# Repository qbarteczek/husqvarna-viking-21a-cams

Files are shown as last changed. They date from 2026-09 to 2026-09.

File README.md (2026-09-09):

# Generator bębnów ściegowych do Husqvarna 21E / Husqvarna 21E Stitch Drum Generator

*Dokument dwujęzyczny — polski niżej, English below. / Bilingual document — Polish first, English below.*

---

> [!TIP]
> ### 🌐 [URUCHOM GENERATOR BĘBNÓW ONLINE (BEZ INSTALOWANIA PROGRAMÓW)](https://qbarteczek.github.io/husqvarna-viking-21a-cams/)
> **Dla każdego użytkownika maszyny:** wybierz dowolne ściegi z katalogu kilkudziesięciu wzorów, zobacz bęben w 3D w czasie rzeczywistym i pobierz gotowy plik `.stl` do druku 3D jednym kliknięciem!
> 
> *English: [CLICK HERE TO LAUNCH THE 3D DRUM GENERATOR IN BROWSER (NO SOFTWARE NEEDED)](https://qbarteczek.github.io/husqvarna-viking-21a-cams/)*

---

## PL

Otwarty **generator** bębnów ściegowych (stitch cams) do maszyny **Husqvarna 21E**
(rodzina mechanizmu obejmuje też pokrewne oznaczenia: 19, 20, 21A). Nie jest to
zamknięty zestaw czterech wzorów — to parametryczna biblioteka i aplikacja internetowa, w której
mocowanie jest raz zweryfikowane i wspólne, a Ty projektujesz dowolną liczbę
własnych wzorów ściegów. Patrz [`docs/CREATING_NEW_DRUMS.md`](docs/CREATING_NEW_DRUMS.md).

### Cel

Zestaw A jest już zaprojektowany: [Viking 21a Basic Stitch Cam](https://www.thingiverse.com/thing:6018240)
autorstwa maxkrippler — zygzak + zygzak 3-stopniowy. Geometrię zweryfikowano dwoma
niezależnymi źródłami:

1. **Analiza pliku STL** zestawu A (skan promienia co 0.1–0.25 mm wzdłuż całej długości) —
   wykazała, że to nie płaska tarcza, tylko **krzywka bębnowa z profilowaną krawędzią**:
   - sama krawędź walca na każdej z 5 pozycji jest ukształtowana jako ząbki/profil ściegu
     (nie schowany rowek) — czujnik/popychacz maszyny jeździ bezpośrednio po tej krawędzi,
   - pozycje **sąsiadują bezpośrednio, bez żadnego odstępu**,
   - krzywka **nie ma otworu przelotowego na wałek** — ma za to gniazdo montażowe (otwór na
     wałek napędowy z wypustem blokującym obrót) w czole dużego kołnierza oraz osobny,
     wieloschodkowy trzpień montażowy między dużym kołnierzem a częścią zębatą.
2. **Zdjęcia fizycznego bębna A** (dostarczone przez użytkownika, patrz
   [`references/husqvarna_photos_A/`](references/husqvarna_photos_A/)) — ujawniły dodatkowo
   gwint na dużym kołnierzu, dokładny kształt wpustu w gnieździe i układ grawerunku
   ("HUSQVARNA SWEDEN" + litera zestawu).

Na tej podstawie zbudowano parametryczny generator OpenSCAD z trzema gotowymi, oryginalnymi
zestawami — **B1, C1, D** — z tą samą, zweryfikowaną geometrią mocowania. Zestawy A1, B1, C1
stanowią wierną rekonstrukcję historycznych bębnów fabrycznych z oficjalnej instrukcji
obsługi Husqvarna 21E (str. 31) oraz instrukcji serwisowej Class 21.

### Status

| Zestaw | Oznaczenie fabryczne | Źródło wzorów | Status |
|---|---|---|---|
| **A1** | `S 41-10950` | Instrukcja 21E (str. 31) + zdjęcia bębna A | Pełna rekonstrukcja fabryczna (`models/generated/cam_A.scad` + `.stl`) |
| **B1** | `S 41-10951` | Instrukcja 21E (str. 31: *Grunnmönster B1*) | Pełna rekonstrukcja fabryczna (`models/generated/cam_B.scad` + `.stl`) |
| **C1** | `S 41-10952` | Instrukcja 21E (str. 31: *Grunnmönster C1*) | Pełna rekonstrukcja fabryczna (`models/generated/cam_C.scad` + `.stl`) |
| **D**  | — | Wzór autorski (ściegi użytkowe specjalne) | Wygenerowany (`models/generated/cam_D.scad` + `.stl`) |

Element pomocniczy [`tools/openscad/mating_shaft_reference.scad`](tools/openscad/mating_shaft_reference.scad)
— testowy trzpień do sprawdzenia dopasowania otworu i wpustu przed drukiem całego bębna.

### Generator nowych bębnów (Stitch Drum Generator)

Projekt zawiera uniwersalny generator umożliwiający stworzenie własnego bębna z **katalogu ponad 35 znanych ściegów** (użytkowe, elastyczne, ozdobne fale, satynowe romby, meandry i szachownice):
1. **🌐 Interaktywna aplikacja online ([https://qbarteczek.github.io/husqvarna-viking-21a-cams/](https://qbarteczek.github.io/husqvarna-viking-21a-cams/)):**
   - **Podgląd 3D w czasie rzeczywistym (WebGL / Three.js):** natychmiastowe obracanie i oglądanie bębna (koniec z czekaniem 30–40 s na renderowanie OpenSCAD),
   - **Bezpośrednie generowanie STL:** klikasz „Pobierz plik STL do druku 3D” i w 0.01 sekundy pobierasz gotowy plik `.stl` gotowy do slicera (Cura, PrusaSlicer, Bambu Studio),
   - **Symulacja przeszycia na tkaninie:** podgląd nici igłowej na żywo dla 5 pozycji bębna,
   - **Offline:** dwuklik w plik `Uruchom_Generator.bat` w katalogu projektu.
2. **Panel okienkowy OpenSCAD Customizer GUI** ([`tools/openscad/cam_generator.scad`](tools/openscad/cam_generator.scad)): rozwijane menu wyboru ściegów dla każdej pozycji bezpośrednio w OpenSCAD bez pisania kodu.
3. **Skrypt wsadowy PowerShell** ([`tools/generator/generate_drum.ps1`](tools/generator/generate_drum.ps1)): automatyczne generowanie kodu i kompilacja siatki STL z wiersza poleceń.

Szczegółowy podręcznik użytkownika: [`docs/GENERATOR.md`](docs/GENERATOR.md) / [`docs/GENERATOR.en.md`](docs/GENERATOR.en.md).
Zobacz też: [`docs/CREATING_NEW_DRUMS.md`](docs/CREATING_NEW_DRUMS.md) dla projektowania własnych funkcji matematycznych.

### Podgląd

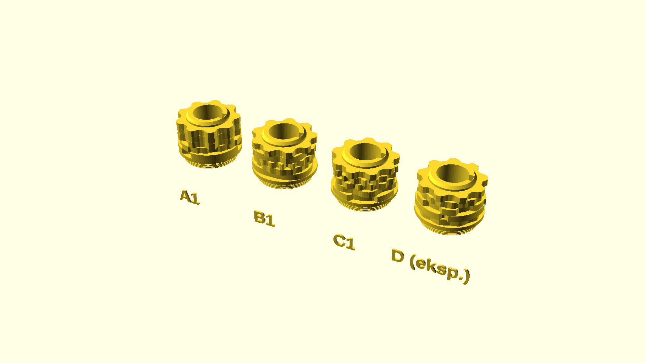
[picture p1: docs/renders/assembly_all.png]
Zestawienie A1/B1/C1/D


| Bęben | Widok izometryczny 3D | Czoło z grawerunkiem i wpustem |
|:---:|:---:|:---:|
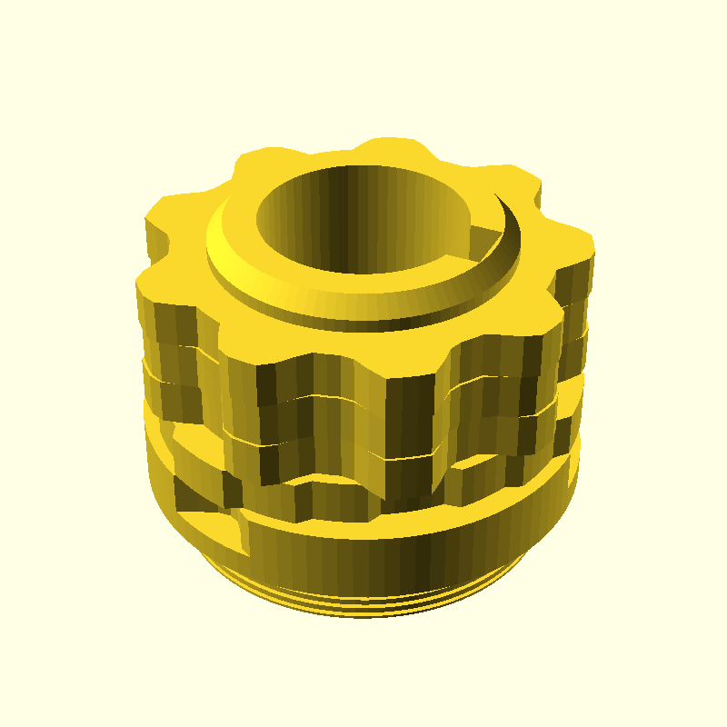
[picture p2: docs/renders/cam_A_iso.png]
A1 iso
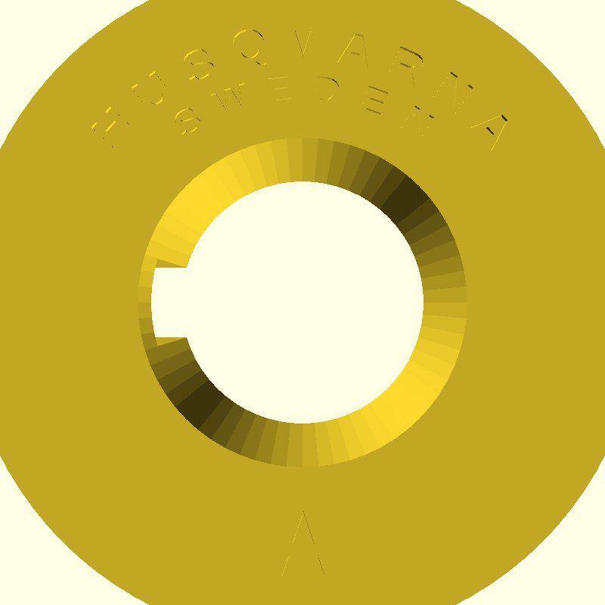
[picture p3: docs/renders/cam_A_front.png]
A1 czoło
| **A1** (fabryczny) |  |  |
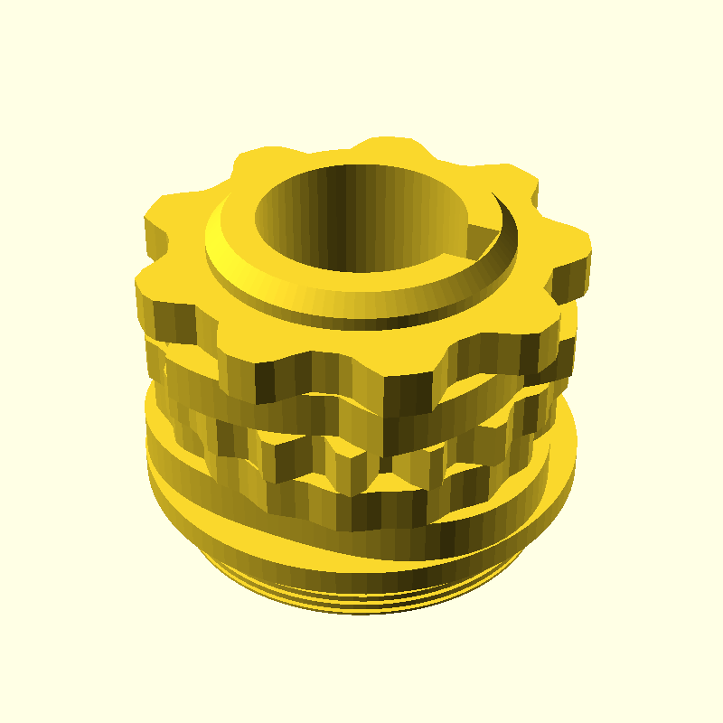
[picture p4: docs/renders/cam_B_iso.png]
B1 iso
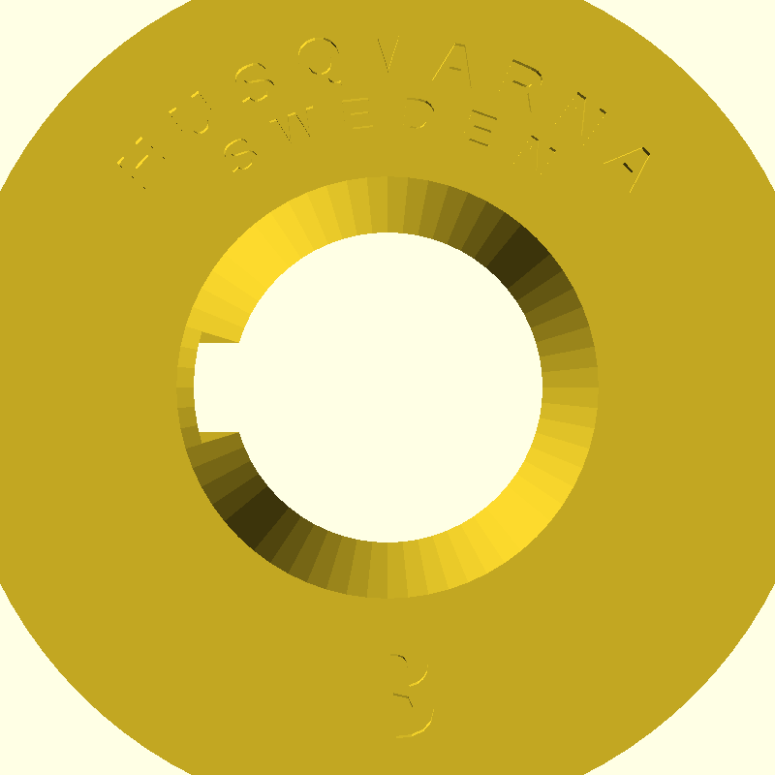
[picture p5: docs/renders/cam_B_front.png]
B1 czoło
| **B1** (fabryczny) |  |  |
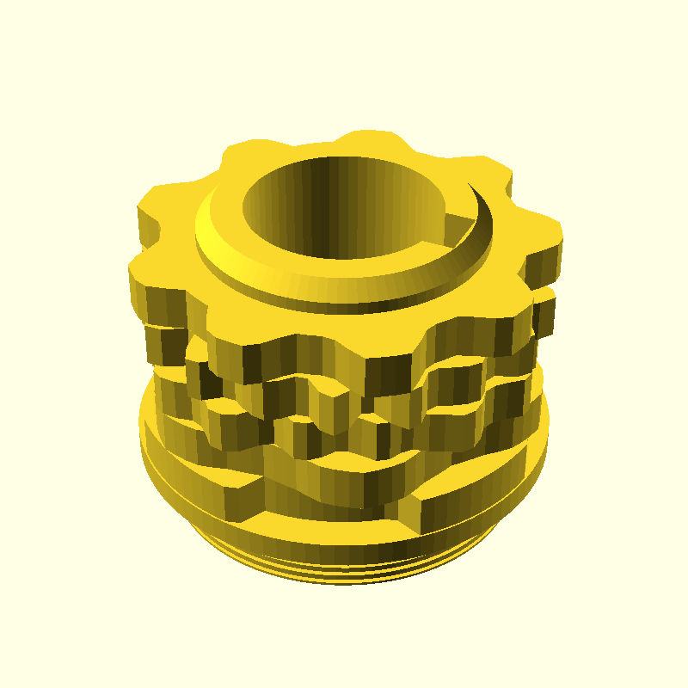
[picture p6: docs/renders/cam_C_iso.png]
C1 iso
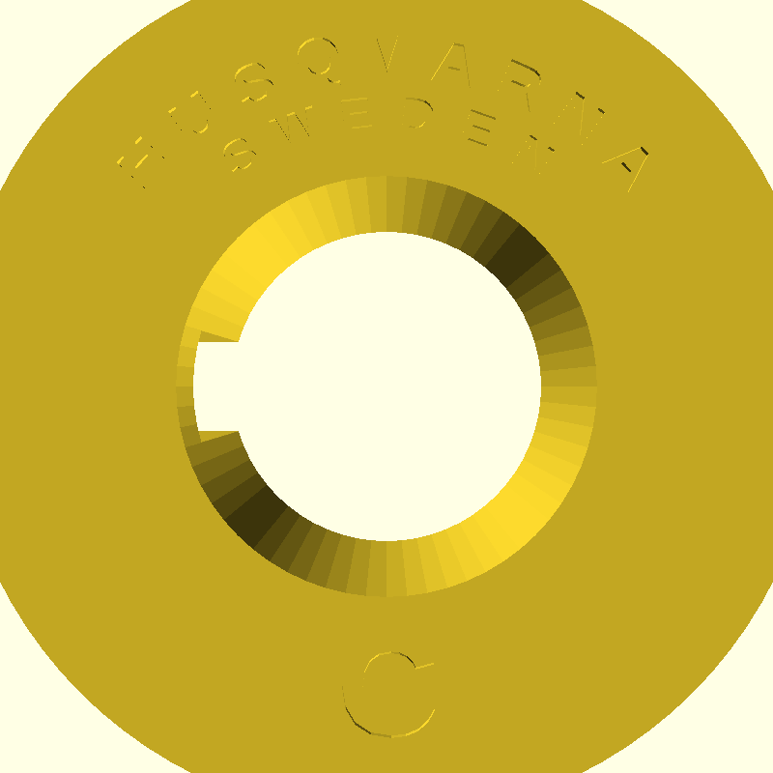
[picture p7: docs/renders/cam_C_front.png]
C1 czoło
| **C1** (fabryczny) |  |  |
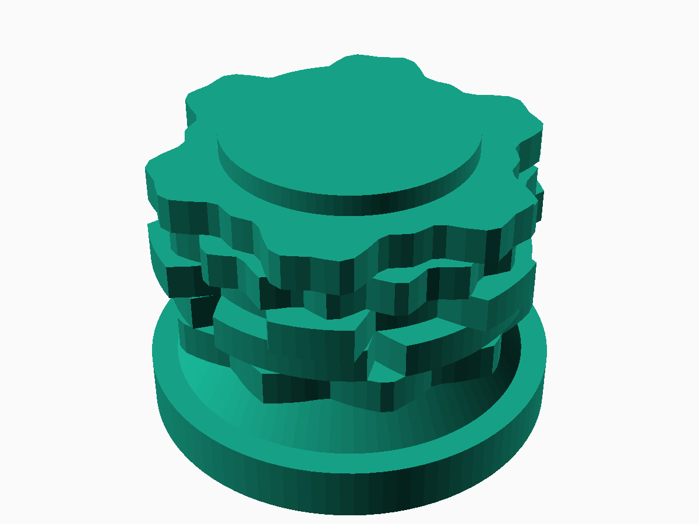
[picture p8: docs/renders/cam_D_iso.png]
D iso
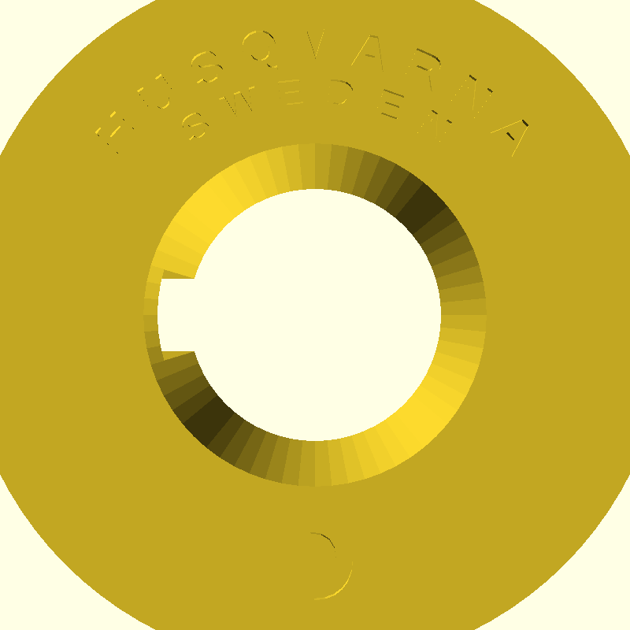
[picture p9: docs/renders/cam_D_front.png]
D czoło
| **D** (autorski) |  |  |

Więcej widoków (z przodu) w [`docs/renders/`](docs/renders/).

### Dokumentacja

| Plik | Zawartość |
|---|---|
| [`docs/DIMENSIONS.md`](docs/DIMENSIONS.md) | Wymiary mechaniczne (STL + zdjęcia fizycznego bębna) |
| [`docs/STITCH_DESIGN.md`](docs/STITCH_DESIGN.md) | Wybór i uzasadnienie wzorów ściegów B/C/D, kalibracja |
| [`docs/CREATING_NEW_DRUMS.md`](docs/CREATING_NEW_DRUMS.md) | Jak zaprojektować i wygenerować własny bęben |
| [`docs/PRINTABILITY.md`](docs/PRINTABILITY.md) | Analiza drukowalności, orientacja, parametry druku |
| [`docs/USAGE.md`](docs/USAGE.md) | Montaż bębna w maszynie, wybór ściegu, bezpieczeństwo |
| [`docs/WORKFLOW.md`](docs/WORKFLOW.md) | Jak renderować/rozwijać projekt dalej |
| [`docs/renders/`](docs/renders/) | Podglądowe renderowania (różne rzuty + zestawienie) |

Każdy z powyższych ma wersję angielską pod nazwą `*.en.md` w tym samym folderze.

### Struktura

- `models/original/` — geometria zestawu A po imporcie/analizie pliku źródłowego,
- `models/generated/` — bębny B, C, D oraz natywna wersja A (`cam_A.scad`),
- `references/` — zdjęcia fizycznego bębna A, linki źródłowe,
- `docs/` — dokumentacja (PL + EN), renderowania,
- `tools/openscad/` — wspólna biblioteka OpenSCAD (`cam_common.scad`), szablon nowego bębna
  (`cam_template.scad`), element pomocniczy do testu dopasowania
  (`mating_shaft_reference.scad`) i skrypty renderujące (`render/`).

### Projekt źródłowy (zestaw A)

https://www.thingiverse.com/thing:6018240

### Licencja

CC-BY 4.0 — patrz [`LICENSE`](LICENSE) i [`LICENSE_NOTE.md`](LICENSE_NOTE.md) (atrybucja dla
zestawu A / maxkrippler).

---

## EN

An open **generator** of stitch cam drums for the **Husqvarna 21E** sewing machine (the same
mechanism family also covers related designations: 19, 20, 21A). This is not a closed set of
four patterns — it's a parametric OpenSCAD library where the mounting geometry is verified
once and shared, while you design any number of your own stitch patterns. See
[`docs/CREATING_NEW_DRUMS.md`](docs/CREATING_NEW_DRUMS.md).

### Goal

Set A is already designed: [Viking 21a Basic Stitch Cam](https://www.thingiverse.com/thing:6018240)
by maxkrippler — zigzag + 3-step zigzag. The geometry was verified from two independent
sources:

1. **STL file analysis** of set A (radius scan every 0.1–0.25 mm along the full length) —
   showed it's not a flat disc, but a **barrel cam with a profiled edge**:
   - the cylinder's edge itself, at each of the 5 positions, is shaped as the stitch profile
     (teeth), not a hidden groove — the machine's sensor/follower rides directly on this edge,
   - positions are **directly adjacent, with no gap between them**,
   - the cam **has no through-bore for a shaft** — instead it has a mounting socket (a hole
     for the drive shaft with a key that blocks rotation) in the face of the large flange, and
     a separate, multi-step mounting spindle between the large flange and the toothed section.
2. **Photos of the physical drum A** (provided by the user, see
   [`references/husqvarna_photos_A/`](references/husqvarna_photos_A/)) — additionally revealed
   a thread on the large flange, the exact shape of the socket's keyway, and the engraving
   layout ("HUSQVARNA SWEDEN" + the set's letter).

Based on this, a parametric OpenSCAD generator was built with ready-made sets: **A1, B1, C1, D**,
sharing the identical, verified mounting geometry. Sets A1, B1, and C1 are faithful historical
reconstructions based on official factory documentation: the Husqvarna 21E User Manual (p. 31)
and the Viking Class 21 Service Manual.

### Status

| Set | Factory Part No. | Source / Reference | Status |
|---|---|---|---|
| **A1** | `S 41-10950` | 21E Manual (p. 31) + photos of physical drum A | Full factory reconstruction (`models/generated/cam_A.scad` + `.stl`) |
| **B1** | `S 41-10951` | 21E Manual (p. 31: *Grunnmönster B1*) | Full factory reconstruction (`models/generated/cam_B.scad` + `.stl`) |
| **C1** | `S 41-10952` | 21E Manual (p. 31: *Grunnmönster C1*) | Full factory reconstruction (`models/generated/cam_C.scad` + `.stl`) |
| **D**  | — | Custom pattern (special utility stitches) | Generated (`models/generated/cam_D.scad` + `.stl`) |

Auxiliary part [`tools/openscad/mating_shaft_reference.scad`](tools/openscad/mating_shaft_reference.scad)
— a test pin for checking the hole/key fit before printing a whole drum.

### Custom Stitch Drum Generator

The project includes an open generator suite allowing users to create custom stitch drums from a **catalog of 35+ verified stitches** (utility, stretch, decorative waves, modulated satin, meanders, and checkerboards):
1. **🌐 Interactive Web Application ([https://qbarteczek.github.io/husqvarna-viking-21a-cams/](https://qbarteczek.github.io/husqvarna-viking-21a-cams/)):**
   - **Real-Time 3D Drum View (WebGL / Three.js):** Instant rendering without waiting 30–40 s for CSG compile in OpenSCAD.
   - **Direct STL Export:** 1-click download of a watertight, 3D-printable `.stl` file in 0.01 seconds directly in your browser.
   - **Live Thread Simulation:** Visual stitch representation on virtual fabric across 5 positions.
   - **Offline Mode:** Simply double-click `Uruchom_Generator.bat` in the root folder.
2. **OpenSCAD Customizer GUI** ([`tools/openscad/cam_generator.scad`](tools/openscad/cam_generator.scad)): native dropdown menus to pick stitches for each position without writing code.
3. **PowerShell CLI Script** ([`tools/generator/generate_drum.ps1`](tools/generator/generate_drum.ps1)): command-line automation for code generation and one-step STL compilation.

User Guide: [`docs/GENERATOR.en.md`](docs/GENERATOR.en.md) / [`docs/GENERATOR.md`](docs/GENERATOR.md).
See also: [`docs/CREATING_NEW_DRUMS.md`](docs/CREATING_NEW_DRUMS.md) for custom mathematical curve design.

### Preview

A1/B1/C1/D lineup

| Drum | 3D Isometric View | Front Dial & Keyway Face |
|:---:|:---:|:---:|
| **A1** (factory) | A1 iso | A1 front |
| **B1** (factory) | B1 iso | B1 front |
| **C1** (factory) | C1 iso | C1 front |
| **D** (custom) | D iso | D front |

More views (front) in [`docs/renders/`](docs/renders/).

### Documentation

| File | Content |
|---|---|
| [`docs/DIMENSIONS.en.md`](docs/DIMENSIONS.en.md) | Mechanical dimensions (STL + photos of the physical drum) |
| [`docs/STITCH_DESIGN.en.md`](docs/STITCH_DESIGN.en.md) | Choice and rationale for the B/C/D stitch patterns, calibration |
| [`docs/CREATING_NEW_DRUMS.md`](docs/CREATING_NEW_DRUMS.md) | How to design and generate your own drum (bilingual) |
| [`docs/PRINTABILITY.en.md`](docs/PRINTABILITY.en.md) | Printability analysis, orientation, print settings |
| [`docs/USAGE.en.md`](docs/USAGE.en.md) | Mounting the drum in the machine, selecting a stitch, safety |
| [`docs/WORKFLOW.en.md`](docs/WORKFLOW.en.md) | How to render/extend the project further |
| [`docs/renders/`](docs/renders/) | Preview renders (various views + lineup) |

### Structure

- `models/original/` — set A geometry, imported/analyzed from the source file,
- `models/generated/` — drums B, C, D, plus a native version of A (`cam_A.scad`),
- `references/` — photos of the physical drum A, source links,
- `docs/` — documentation (PL + EN), renders,
- `tools/openscad/` — the shared OpenSCAD library (`cam_common.scad`), the new-drum template
  (`cam_template.scad`), the fit-test auxiliary part (`mating_shaft_reference.scad`), and the
  rendering scripts (`render/`).

### Source project (set A)

https://www.thingiverse.com/thing:6018240

### License

CC-BY 4.0 — see [`LICENSE`](LICENSE) and [`LICENSE_NOTE.md`](LICENSE_NOTE.md) (attribution for
set A / maxkrippler).

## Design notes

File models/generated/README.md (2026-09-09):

# Wygenerowane modele bębnów ściegowych (A1, B1, C1, D)

Katalog zawiera gotowe modele parametryczne OpenSCAD (`.scad`) oraz wyrenderowane bryły siatek trójwymiarowych (`.stl`), gotowe do bezpośredniego pocięcia w slicerze i druku 3D.

## Dostępne bębny

| Plik SCAD | Plik STL | Oznaczenie fabryczne | Status / Źródło |
|---|---|---|---|
| [`cam_A.scad`](cam_A.scad) | [`cam_A.stl`](cam_A.stl) | `S 41-10950` | Pełna rekonstrukcja bębna standardowego A1 (ścieg kryty, trójskok, zygzaki) |
| [`cam_B.scad`](cam_B.scad) | [`cam_B.stl`](cam_B.stl) | `S 41-10951` | Pełna rekonstrukcja bębna ozdobnego B1 (serpentyna, satynowy romb, ząbki) |
| [`cam_C.scad`](cam_C.scad) | [`cam_C.stl`](cam_C.stl) | `S 41-10952` | Pełna rekonstrukcja bębna meandrowego C1 (grecki meander, bloki satynowe, klepsydra) |
| [`cam_D.scad`](cam_D.scad) | [`cam_D.stl`](cam_D.stl) | — | Zestaw autorski eksperymentalny (drabinka, potrójny elastyczny) |

## Element pomocniczy

* [`../../tools/openscad/mating_shaft_reference.scad`](../../tools/openscad/mating_shaft_reference.scad) — testowy próbnik wałka i wpustu przed drukiem pełnego bębna.

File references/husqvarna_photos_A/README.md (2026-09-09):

# Zdjęcia fizycznego bębna A / Physical drum A photos

Zdjęcia własne użytkownika (nie materiał zewnętrzny), fizycznego, oryginalnego bębna
oznaczonego "A" wymontowanego z maszyny — 10 z 46 zrobionych, wybranych jako
najbardziej informacyjne. Pełny zestaw pozostaje lokalnie u użytkownika
(`C:\Users\Qbart\Downloads\husqvarna\`).

User's own photos (not third-party material) of the physical, original drum marked "A"
removed from the machine — 10 out of 46 taken, selected as most informative. The full set
stays local to the user.

| Plik / File | Co pokazuje / What it shows |
|---|---|
| `01_overview_thread_end.jpg` | Ogólny widok, koniec z gwintem / Overview, threaded end |
| `02_overview_angle.jpg` | Ogólny widok pod innym kątem / Overview, different angle |
| `03_engraving_husqvarna_sweden_A.jpg` | Grawerunek "HUSQVARNA SWEDEN A" / Engraving "HUSQVARNA SWEDEN A" |
| `04_engraving_angle.jpg` | Grawerunek pod kątem / Engraving at an angle |
| `05_engraving_closeup.jpg` | Zbliżenie na grawerunek / Engraving close-up |
| `06_side_profile_full_length.jpg` | Profil boczny, cała długość / Side profile, full length |
| `07_side_profile_thread_visible.jpg` | Profil boczny, widoczne zwoje gwintu / Side profile, thread turns visible |
| `08_far_end_gear_collar_keyway.jpg` | Daleki koniec: kołnierz zębaty + wpust / Far end: gear collar + keyway |
| `09_far_end_keyway_closeup.jpg` | Zbliżenie na wpust dalekiego końca / Close-up of the far-end keyway |
| `10_toothed_body_pattern.jpg` | Wzór "szachownicy" na części zębatej / "Checkerboard" pattern on the toothed body |

Wykorzystane do poprawek geometrii opisanych w [`../../docs/DIMENSIONS.md`](../../docs/DIMENSIONS.md)
(sekcja "Poprawki na podstawie zdjęć fizycznego bębna A"): gwint na dużym kołnierzu, wpust
w gnieździe montażowym, dokładny układ grawerunku.

Used for the geometry corrections described in [`../../docs/DIMENSIONS.md`](../../docs/DIMENSIONS.md)
("Corrections based on photos of the physical drum A" section): thread on the large flange,
keyway in the mounting socket, exact engraving layout.

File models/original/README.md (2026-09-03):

# Modele oryginalne (zestaw A)

Wklej tu zawartość paczki pobranej z https://www.thingiverse.com/thing:6018240
(pliki `.stl` i/lub `.scad` zestawu A — Husqvarna Viking 21A, zygzak + zygzak 3-stopniowy).

Po dodaniu plików napisz mi, żebym mógł je odczytać i wyciągnąć wymiary mechaniczne
do `docs/DIMENSIONS.md`.

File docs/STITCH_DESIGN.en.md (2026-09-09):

# Stitch Patterns — Factory Sets A1, B1, C1 and Extended Set D

## Historical Sources and Factory Specifications

The geometry and stitch profiles have been reconstructed using original factory technical documentation:
1. **Husqvarna Automatic 21 E User Manual** (`Husqvarna-21E_User-Manual_NO.pdf`):
   - Page 31: *Grunnmönster for kammene A1, B1 og C1* — official table of settings (stitch width and length) and stitch sample photographs,
   - Page 25: *Mönsternøkkelen* — pattern selection wheel for 1-needle and twin-needle (2 mm) stitching,
   - Pages 27, 29, 30: catalog numbers, cam replacement procedure on position 5,
   - Page 55: catalog listing of accessories and parts.
2. **Viking Automatic class 21 Service Manual** (`Husqvarna-Class-21_Service-Manual_EN.pdf`):
   - Section 1 (p. 1): calibration of minimum follower play at the high point of the cam (`EDGE_MAX_R = 17.03 mm`) on **position 5**,
   - Section 2 (p. 1): needle swing timing — sideways needle bar frame movement terminates when needle tip is at least 7 mm above throat plate (justifying flat dwell periods on trapezoidal tooth profiles).

---

## Operating Principle

Each drum features **5 axial positions** (`N_POS = 5`) spanning $Z \in [6.4, 23.6]\text{ mm}$ (track width `BAND_LEN = 3.44 mm`).
The stitch selector (*Mönstervelger*, 1–5 on the front dial) slides the contact follower along the camshaft axis.
The follower rides directly on the profiled outer edge:
* At maximum radius (`EDGE_MAX_R = 17.03 mm`, normalized `-1`), the needle bar rests at the far left (straight stitch baseline).
* At the tooth valley bottom (`EDGE_MIN_R = 14.20 mm`, normalized `+1`), the needle bar performs full sideways deflection to the right (radial tooth swing `EDGE_SWING = 2.83 mm`).

---

## Set A1 — Standard Drum (`S 41-10950`)

Factory standard drum supplied inside the machine (*"i maskinen"*).

| Pos. | Manual Stitch Name | Factory Setting (W / L) | Mathematical Function | Description |
|:---:|:---|:---:|:---|:---|
| **1** | **Blind hem / picot** (*Usynlig faldsöm / Picot*) | 4 / 0.3 | `blind_hem(a, 3, 0.20)` | 4–5 straight stitches on left + single spike to right for blind hems. |
| **2** | **3-step elastic zig-zag** (*Trestings siksak / Quick-Stopp*) | 4 / 0.3 | `three_step_zigzag(a, 3)` | 3 steps right, 3 steps left — knit joining, elastic insertion, mending. |
| **3** | **Wide zig-zag** | 4 / 1.0 | `trap_wave(a, 9, 0.28) * 0.95` | Extended pitch zig-zag for seam finishing. |
| **4** | **Dense darning zig-zag** | 4 / 0.3 | `trap_wave(a, 9, 0.28) * 0.80` | Fine satin stitch. |
| **5** | **Standard reference zig-zag** | 4 / 1.5 | `trap_wave(a, 9, 0.28) * 0.95` | Mechanism rest/zero position, baseline for cam removal. |

---

## Set B1 — Accessory Drum (`S 41-10951`)

Decorative and curved wavy stitch set.

| Pos. | Manual Stitch Name | Factory Setting (W / L) | Mathematical Function | Description |
|:---:|:---|:---:|:---|:---|
| **1** | **Serpentine / wavy stitch** (*Slangesöm*) | 4 / 1.5 | `sine_wave(a, 3) * 0.90` | Smooth sine wave with gentle curves. |
| **2** | **Stepped chevron / dense wave** | 4 / 0.3 | `tri_wave(a, 3)*0.70 + tri_wave(a, 18)*0.25` | Angled wave combined with fine micro-teeth. |
| **3** | **Satin diamond / leaf / pearls** (*Diamantsöm*) | 4 / 0.3 | `diamond_satin(a, 18, 3)` | Amplitude-modulated satin zigzag expanding and tapering into diamonds. |
| **4** | **Angled teeth / saw** (*Tannsöm*) | 4 / 0.3 | `saw_wave(a, 6, 0.80) * 0.90` | Asymmetrical sawtooth wave with steep return. |
| **5** | **Standard reference zig-zag** | 4 / 1.5 | `trap_wave(a, 9, 0.28) * 0.95` | Rest position and reference track. |

---

## Set C1 — Accessory Drum (`S 41-10952`)

Geometric and meander stitch set.

| Pos. | Manual Stitch Name | Factory Setting (W / L) | Mathematical Function | Description |
|:---:|:---|:---:|:---|:---|
| **1** | **Greek key / crenelated meander** (*Mekaniskt meander / Tinn*) | 4 / 0.3 | `trap_wave(a, 4, 0.45) * 0.90` | Rectangular crenelations with dense coverage. |
| **2** | **Flame stitch / sharp triangle** (*Flammesöm*) | 4 / 0.3 | `arrow_sharpen(a, 6, 0.50) * 0.90` | Sharpened triangular teeth. |
| **3** | **Satin blocks** (*Blokksöm*) | 4 / 0.3 | `block_satin(a, 16, 4)` | Alternating left/right shifted rectangular satin panels. |
| **4** | **Hourglass / double diamond** | 4 / 0.3 | `hourglass_satin(a, 18, 3)` | Symmetrical taper creating an hourglass shape. |
| **5** | **Standard reference zig-zag** | 4 / 1.5 | `trap_wave(a, 9, 0.28) * 0.95` | Rest position and reference track. |

---

## Set D — Extended / Experimental Set

Experimental custom utility set.

| Pos. | Stitch Name | Settings (W / L) | Mathematical Function | Description |
|:---:|:---|:---:|:---|:---|
| **1** | **Narrow reference zig-zag** | 2 / 1.0 | `tri_wave(a, 10) * 0.40` | Fine precision zig-zag. |
| **2** | **Reinforced blind stitch** | 4 / 0.5 | `blind_hem(a, 4, 0.15)` | Sparsely spaced lateral bites. |
| **3** | **Ladder stitch** | 4 / 0.5 | `sign(sine_wave(a, 6)) * 0.85` | Dual parallel rails with abrupt shifts. |
| **4** | **Triple stretch straight** | 1 / 1.5 | `tri_wave(a, 18) * 0.30` | Fast micro-oscillation for seam strength. |
| **5** | **Standard reference zig-zag** | 4 / 1.5 | `trap_wave(a, 9, 0.28) * 0.95` | Rest position. |

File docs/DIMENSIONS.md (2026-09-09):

# Wymiary mechaniczne — bęben ściegowy Husqvarna 21E (rodzina 19/20/21A/21E)

Źródło geometrii: bezpośrednia analiza 46 zdjęć w wysokiej rozdzielczości fizycznego bębna A użytkownika oraz adnotacji i korekt naniesionych na render testowy.

## Podsumowanie geometrii bębna

Bęben ma całkowitą długość osiową **26.0 mm** (oś obrotu Z). Składa się z następujących sekcji wzdłuż osi Z:

| Odcinek Z [mm] | Długość [mm] | Promień / Wymiar | Opis elementu |
|---|---:|---:|---|
| **0.0 – 2.4** | 2.4 | R = 14.5 mm (Ø 29.0 mm) | **Dysk czołowy z 3 rowkami**: Posiada 3 płytkie rowki obwodowe (szer. 0.35 mm, głęb. 0.4 mm). Na płaskim czole (Z=0) wygrawerowano literę zestawu ("A"), napisy "HUSQVARNA" i "SWEDEN" oraz radialne znaczniki indeksujące. |
| **2.4 – 4.4** | 2.0 | R = 11.5 mm (Ø 23.0 mm) | **Szyjka / rowek podcięciowy**: przewężenie oddzielające dysk czołowy od kołnierza głównego. |
| **4.4 – 6.4** | 2.0 | R = 17.03 mm (Ø 34.06 mm) | **Kołnierz główny**: definiuje maksymalną średnicę zewnętrzną bębna, idealnie równą wierzchołkom zębów krzywek (`EDGE_MAX_R`). |
| **6.4 – 23.6** | 17.2 | R = 14.20 – 17.03 mm | **Część robocza krzywek (5 pozycji)**: Zaczyna się **bezpośrednio** przy kołnierzu głównym (brak zbędnej szyjki pośredniej). 5 pozycji po 3.44 mm każda, stykających się bez przerw. Amplituda radialna zębów wynosi **2.83 mm** (szczyty R = 17.03 mm, dno dolin R = 14.20 mm). W bębnie A zęby mają profil trapezu (`trap_wave`, 9 zębów na obrót) z płaskimi szczytami i dolinami (fazy stabilizacji igły). |
| **23.6 – 26.0** | 2.4 | R = 11.5 → 10.3 mm | **Kołnierz tylny (montażowy)**: Walec bazowy o promieniu 11.5 mm, zakończony wyraźną fazą stożkową (dł. 1.4 mm, od Z=24.6 do 26.0) ułatwiającą osadzenie bębna na osi maszyny. |
| **0.0 – 26.0** | 26.0 (przelot) | R = 7.8 mm (Ø 15.6 mm) | **Otwór centralny na wałek maszyny**: Otwór **przelotowy na wylot** przez całą długość bębna. |
| **6.4 – 26.0** | 19.6 (nieprzelotowy) | Szer. 4.5 mm, głęb. 2.2 mm | **Wpust (rowek pod klin)**: Wzdłużny rowek wycięty w ściance otworu od strony tylnego kołnierza (Z=26.0) w głąb bębna aż do płaszczyzny początku strefy krzywek / kołnierza głównego (Z=6.4). **Nie przechodzi przez cały bęben** — nie wychodzi na czoło z grawerunkiem. Od strony czoła (Z=0.0 .. 6.4 mm) otwór tworzy jednolitą, gładką tuleję łożyskową (dysk czołowy 2.4 mm + przewężenie szyjki 2.0 mm + kołnierz główny 2.0 mm = 6.4 mm litej ścianki), co zapobiega osłabieniu przewężenia szyjki i chroni grawerunek czołowy. |

---

## Szczegółowe omówienie korekt fizycznych

Na podstawie zdjęć oryginału oraz rysunku z adnotacjami użytkownika rozwiązano wszystkie rozbieżności:

1. **Dysk zewnętrzny z 3 rowkami (żółta strzałka)**:
   - Wcześniej błędnie interpretowany jako helisa/gwint. W rzeczywistości to dysk o średnicy Ø 29.0 mm z trzema równoległymi, płytkimi rowkami obwodowymi.
2. **Kołnierz główny (niebieska strzałka)**:
   - Kołnierz ten wyznacza maksymalną średnicę zewnętrzną bębna i jest równy maksymalnej amplitudzie zębów krzywki (`EDGE_MAX_R = 17.03 mm`, Ø 34.06 mm).
3. **Ciągłość krzywek (czerwona strzałka)**:
   - Zlikwidowano sztuczną wnękę/szyjkę pomiędzy kołnierzem a krzywkami. Ścieżki krzywek zaczynają się bezpośrednio na ściance kołnierza głównego (przy Z = 6.4 mm).
4. **Otwór przelotowy i precyzyjny zakres wpustu (określony ze zdjęć)**:
   - Główny otwór cylindryczny na wałek jest przelotowy na wylot (Ø 15.6 mm).
   - **Wpust (rowek pod klin wałka)** wprowadzany jest od strony tylnego kołnierza montażowego ($Z = 26.0\text{ mm}$ — zdjęcia `08_far_end_gear_collar_keyway.jpg`, `09_far_end_keyway_closeup.jpg`, `IMG_20260909_081514.jpg`).
   - Biegnie przez strefę krzywek ($Z = 6.4 \dots 23.6\text{ mm}$) i tylny kołnierz ($Z = 23.6 \dots 26.0\text{ mm}$).
   - **Koniec wpustu ($Z = 6.4\text{ mm}$)**: jak widać na zdjęciach pod kątem od strony czoła (`04_engraving_angle.jpg`, `05_engraving_closeup.jpg`), wpust kończy się ślepym prostopadłym uskokiem na głębokości $6.4\text{ mm}$ od czoła. Czoło bębna, przewężenie szyjki (gdzie ścianka przy $R=11.5\text{ mm}$ byłaby zbyt cienka, gdyby wpust wchodził głębiej) oraz kołnierz tworzą $6.4\text{ mm}$ jednolitej tulei bez wycięcia wpustowego. Całkowita długość wpustu wynosi **19.6 mm** ($Z \in [6.4, 26.0]\text{ mm}$).
5. **Kołnierz tylny ze ścięciem stożkowym**:
   - Tylny kołnierz (od Z = 23.6 mm) posiada wyraźne sfazowanie stożkowe wprowadzające, zgodne ze zdjęciami oryginału.
6. **Kształt zębów krzywki A**:
   - Oryginalne zęby na bębnie A nie są ostrymi falami trójkątnymi, lecz falami trapezowymi (`trap_wave`) z płaską półką na szczycie i w dolinie (dwell), co odpowiada czasowi zatrzymania mechanizmu popychacza igły w skrajnych położeniach podczas wbicia igły w materiał.
7. **Skorygowana amplituda zębów krzywek**:
   - Zredukowano przesadną amplitudę (wcześniej 5.03 mm) do realistycznych **2.83 mm** (`EDGE_MAX_R = 17.03 mm`, `EDGE_MIN_R = 14.20 mm`). Na zdjęciach bębna dno ząbków leży zaledwie tuż poniżej krawędzi dysku czołowego (R = 14.5 mm) i znacznie powyżej tylnego kołnierza (R = 11.5 mm).
8. **Orientacja napisów czołowych od lewej do prawej**:
   - Napisy "HUSQVARNA" oraz "SWEDEN" biegną po łuku od lewej do prawej z naturalną orientacją czytania. Litera zestawu ("A") znajduje się czytelnie na dole, a po bokach umieszczone są oryginalne znaczniki indeksujące.

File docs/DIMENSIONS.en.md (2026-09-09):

# Mechanical dimensions — set A (reference)

*(Polish original: [`DIMENSIONS.md`](DIMENSIONS.md))*

Source: `V21ZZ3Z.stl` from the [thing:6018240](https://www.thingiverse.com/thing:6018240)
package (Viking 21a Basic Stitch Cam, maxkrippler). Dimensions extracted by directly
analyzing the STL mesh vertices (radius scan `sqrt(x²+z²)` as a function of position along
the Y axis, in 0.1–0.25 mm steps), not with a CAD tool (none available in this environment).

## Mechanism type — four corrections across successive, increasingly precise analyses

1. This is **not a flat, profiled disc** (like Elna Supermatic cams), but a barrel/drum cam
   with 5 axial positions.
2. The stitch profile is **the cylinder's edge itself** (teeth), not a hidden groove — the
   machine's sensor rides directly on the edge. Positions are **directly adjacent, with no
   gap**.
3. The cam **has no bore running through its full length**. What was earlier taken for a
   "central hole" is actually: (a) **a hole for the machine's drive shaft, with a key**, cut
   into the face of the large flange — the key is **essential for transmitting rotary
   motion** from the shaft to the drum (not a cosmetic detail) — and (b) a separate, narrower
   **mounting spindle** that's part of a multi-step neck between the large flange and the
   toothed section. Everything else is solid.
4. The machine's sensor/follower has a **limited, hard range of motion**: a full radius scan
   of the toothed section (Y=9.7–24.25) shows the edge radius in the original never leaves
   **[7.71 mm, 17.03 mm]** — this is a physical limit of the sensor's reach in the machine's
   mechanism, not an arbitrary design parameter. An earlier version of B/C/D used a lower
   bound of 6.5 mm (outside this range), chosen purely for print-strength reasons without
   reference to the sensor's real reach — corrected.

## Measured dimensions (rotation axis = Y in the original file)

The Y coordinate runs from 0 (large flange, the side with the visible mounting structure) to
26.01 (small flange at the opposite end).

| Segment (Y) | Radius | Description |
|---|---:|---|
| Y = 0 (face) | Ø 29.94 mm (r 14.97) outer, shaft hole r ≈ 7.8 mm at center, with a key | face of the large flange — hole for the machine's drive shaft (the key transmits rotation) |
| Y = 0 – 3.2 | r = 14.97 mm | large flange (solid, apart from the hole in the face) |
| Y = 3.2 – 3.7 | 14.97 → 9.75 mm | conical transition / shoulder |
| Y = 3.7 – 5.8 | r = 9.75 mm | constant intermediate neck |
| Y = 5.8 – 6.3 | 9.75 → 13.97 mm | conical transition / shoulder (radius increases again!) |
| Y = 6.3 – 7.3 | r = 13.97 mm | constant intermediate collar |
| Y = 7.3 – 7.8 | 13.97 → 7.75 mm | conical transition / shoulder |
| Y = 7.8 – 9.7 | r = 7.75 mm | **mounting spindle** (the narrowest section of the neck) |
| Y = 9.7 – ~24.25 | r = **7.71–17.03 mm** (variable, never outside this range) | toothed section — 5 stitch positions, directly adjacent |
| Y = ~24.25 – 26 | r → 10.30 mm | taper to the small flange at the far end |

Depth of the shaft hole from the Y=0 face: approx. 2.5 mm (to be confirmed — the mesh
measurement doesn't unambiguously resolve the exact floor, only the hole's presence and
radius).

**Note:** the table above describes exactly what is in the `V21ZZ3Z.stl` file (a third-party
replica). The generated drums (`cam_common.scad`) **no longer literally reproduce** the stepped
spindle at Y=3.2–9.7 from this table — based on the user's annotations on the physical drum
(section below), it was replaced with a single smooth taper, because the literal reproduction
created a recess in the render that doesn't exist on the real part. The STL remains reliable for
flange radii and the toothed section's reach, but not for the detail of this particular
transition.

## Corrections based on photos of the physical drum A

The user supplied a series of photos of the physical, original drum A (not an STL file) —
folder [`references/husqvarna_photos_A/`](../references/husqvarna_photos_A/) (see also its
README). The photos revealed three elements not visible/ambiguous in the STL mesh alone:

1. **Horizontal grooves on the large flange (Y=0–3.2)** — the photos clearly show several
   horizontal grooves right next to the engraved face. **The first version misread these as a
   screw thread** (a helix, `boss0_threaded()`); after the user annotated a render directly
   (see section below), this was corrected to plain horizontal grooves — `ring_grooved()` in
   `cam_common.scad`. Groove depth and spacing were chosen **visually from the photos** — **to
   be verified and possibly corrected once fitted to the machine's actual socket**.
2. **Key in the shaft hole** — the photos show a cut in the hole on the engraved-face side.
   This is a **functional drive element**, not cosmetic — without it the machine's shaft would
   spin freely in the hole without transmitting motion to the drum. Added as
   `SOCKET_KEY_DEPTH`/`SOCKET_KEY_WIDTH` in `cam_common.scad` — **the drum has the keyway (a
   slot cut outward from the hole), the machine's shaft has the key**, see the section below
   on the key/keyway direction fix.
3. **Engraving** — the real drum has "HUSQVARNA" engraved in an arc at the bottom of the
   face, "SWEDEN" below it, and a large, separate letter for the set closer to the hole at
   the top. Reproduced via `arc_text()` / `cam_label_cut()` in `cam_common.scad`.

## Corrections based on the user's annotations on a render

Holding the physical drum A, the user marked up a render with three arrows and an explanation —
the most direct source of correction in this project (a physical object compared against a
render, not a photo interpreted visually):

- **Red arrow** — the stepped mounting spindle (formerly Y=3.2–9.7, narrowing down to a radius
  of ~7.75 mm) created an unintended gap/recess in the render that doesn't exist on the
  physical drum. Fix: removed the narrow steps, replaced with a single smooth taper straight to
  the tooth-valley radius (`EDGE_MIN_R`) — material now fills that whole space, with no segment
  narrower than the tooth valley (`mounting_neck()` in `cam_common.scad`).
- **Yellow arrow** — the feature previously identified as a screw thread **is not a thread** and
  is clearly smaller than the maximum cam amplitude. Fix: replaced `boss0_threaded()` (helix)
  with `ring_grooved()` — plain horizontal grooves with a floor radius (`RING_R`) clearly
  smaller than `EDGE_MAX_R`.
- **Blue arrow** — the engraved flange (`BOSS0`) is wider and it's the one that **defines the
  maximum diameter/amplitude of the cams** — it should have a diameter equal to the maximum
  cam amplitude. Fix: `BOSS0_R = EDGE_MAX_R` directly in `cam_common.scad` (previously 14.97 mm
  and 17.03 mm were independently measured, different values).
- **Chamfer on the face** — the part has a chamfer on the top edge of the face. Added as
  `CHAMFER_LEN` in `boss0_plain()`.
- **Shaft hole with key (the most important correction)** — the earlier version had this
  backwards: a rib protruding **into** the drum's hole (wrong), with the auxiliary
  `mating_shaft_reference.scad` part having a matching slot. Per standard prismatic-key
  convention (and the user's correction, holding the physical drum): **the machine's shaft has
  the key** (a protruding rib), and **the drum has the keyway** — a slot cut **outward** from
  the round hole. Fixed `socket_cut()` (slot instead of rib) and `mating_shaft_reference.scad`
  (protruding key instead of a slot).

**Note on the machine model designation**: this project's documentation previously referred
to "Husqvarna Viking 21A" (following the title of the source file, thing:6018240). The user,
photographing their own physical drum, refers to the machine as **Husqvarna 21E** — this may
be a different variant of the same mechanism family (the 21xx models typically share a
mechanical platform under different market designations), or simply a more accurate
designation of the machine they own. The project name has been updated to "21E"; if this
turns out to be inaccurate in the future, only the name needs to change — the geometry itself
(measured from the real drum and the STL file) remains valid regardless of the exact model
designation.

## What this means for B, C, D

For new sets to physically fit the machine, they must keep:
- the same overall length (26.0 mm),
- the same engraved flange with diameter equal to the maximum cam amplitude
  (`BOSS0_R = EDGE_MAX_R`), the horizontally-grooved ring, and the smooth taper into the
  toothed section,
- the same drive-shaft hole with keyway in the face of the large flange (functional — carries
  the drive; keyway on the drum, key on the machine's shaft),
- the same flange radius at the far end (Ø 20.6 mm at Y=26),
- **no gap between positions** in the toothed section,
- **the same edge-radius range [7.71, 17.03] mm** — no pattern may deflect the sensor beyond
  the limits it physically moves within on the original.

Only **the edge shape (radius as a function of rotation angle)** differs at each of the 5
positions — that's exactly the "stitch pattern" that's designed individually for B, C, D.

## Limitations of this analysis

Dimensions were extracted by analyzing the raw triangle mesh (no access to CAD/OpenSCAD/
Python in this environment) — method: scanning min/max radius in narrow Y bins (0.1–0.25 mm)
and identifying steps/constant segments. Accuracy is on the order of ±0.1 mm for radii, but
the lengths of some short transition segments (shoulders/cones) are approximate — the mesh
resolution didn't always allow a sharp step to be distinguished from a very short cone.
**Before production printing, verification with a test print and comparison against the
original / the machine's actual socket, if available, is recommended.**

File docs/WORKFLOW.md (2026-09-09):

# Workflow

## Wymagania

- OpenSCAD **2021.01 lub nowszy** (pliki używają function literals: `function(a) ...`).
  Na tym komputerze zainstalowany jest `C:\Program Files\OpenSCAD\openscad.exe` (2021.01.22).

## Renderowanie

```powershell
& "C:\Program Files\OpenSCAD\openscad.exe" -o cam_A.stl models\generated\cam_A.scad
& "C:\Program Files\OpenSCAD\openscad.exe" -o cam_B.stl models\generated\cam_B.scad
& "C:\Program Files\OpenSCAD\openscad.exe" -o cam_C.stl models\generated\cam_C.scad
& "C:\Program Files\OpenSCAD\openscad.exe" -o cam_D.stl models\generated\cam_D.scad
& "C:\Program Files\OpenSCAD\openscad.exe" -o mating_shaft_reference.stl tools\openscad\mating_shaft_reference.scad
```

Każda pozycja ściegu to pojedyncze `linear_extrude` wielokąta (profil krawędzi) — szybkie.
Całość: ok. 1.5 minuty na plik bębna, ułamek sekundy na `mating_shaft_reference`
(brak ząbków).

Żeby zobaczyć sam kształt profilu (przekrój), np. do szybkiej kontroli po zmianie wzoru:

```powershell
& "C:\Program Files\OpenSCAD\openscad.exe" -o cross.png --render `
  --camera=0,0,13,0,0,0,55 --projection=o tools\openscad\render\cam_B_cross.scad
```

(`projection(cut=true)` w tych plikach robi przekrój na wysokości Z=13 — środek walca.)

## Kolejność prac

1. Wydrukować `tools/openscad/mating_shaft_reference.scad` i sprawdzić dopasowanie otworu +
   wpustu pryzmatycznego w gnieździe maszyny — szybszy, tańszy test niż całym bębnem
   (patrz `docs/PRINTABILITY.md`).
2. Wydrukować próbnie zestaw A (natywny `cam_A.scad` lub referencyjny plik z
   `models/original/`) i sprawdzić dopasowanie do maszyny — potwierdza poprawność zmierzonych/
   sfotografowanych wymiarów w `docs/DIMENSIONS.md`.
3. Wydrukować próbnie jedną pozycję zestawu B/C/D i porównać szerokość ściegu z zestawem A —
   skalibrować `EDGE_MAX_R` / `EDGE_MIN_R` w `cam_common.scad` jeśli trzeba (patrz
   `docs/PRINTABILITY.md` za uzasadnieniem obecnych wartości i marginesów bezpieczeństwa).
4. Po kalibracji wydrukować pełne zestawy B, C, D — albo zaprojektować własne, patrz
   [`docs/CREATING_NEW_DRUMS.md`](CREATING_NEW_DRUMS.md).
5. Zaktualizować status w tabeli w `README.md` na "przetestowany" po sprawdzeniu fizycznym.

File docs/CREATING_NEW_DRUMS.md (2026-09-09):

# Tworzenie nowych bębnów ściegowych / Creating new stitch drums

*(Polski poniżej / English below)*

## PL

Ten projekt jest pomyślany jako **generator**, nie zamknięty zestaw trzech
wzorów. Mocowanie (kołnierze, gwint, gniazdo, trzpień, dopuszczalny zakres
wychylenia czujnika) jest w całości w `tools/openscad/cam_common.scad` —
każdy nowy bęben automatycznie dziedziczy poprawną, zweryfikowaną geometrię
mechaniczną. Ty projektujesz tylko **5 kształtów krawędzi** (jeden na pozycję
ściegu).

### Krok po kroku

1. Skopiuj [`tools/openscad/cam_template.scad`](../tools/openscad/cam_template.scad)
   do `models/generated/cam_<LITERA>.scad`.
2. Zdefiniuj 5 funkcji `funkcja(a) = ...` — `a` to kąt obrotu w stopniach
   (0–360), wynik to wartość znormalizowana w przybliżeniu `-1..1`. `cam_common.scad`
   sam przeskaluje ją na rzeczywisty promień krawędzi w zmierzonym, bezpiecznym
   zakresie `[EDGE_MIN_R, EDGE_MAX_R]` (patrz `docs/DIMENSIONS.md`) — **nie da
   się** przez pomyłkę zaprojektować wzoru, który wychyli czujnik poza fizyczny
   zasięg mechanizmu.
3. Podmień literę w wywołaniu `cam_with_grooves("X", [...])` — to też steruje
   grawerunkiem na kołnierzu.
4. Wyrenderuj: `openscad.exe -o cam_<LITERA>.stl cam_<LITERA>.scad` (patrz
   `docs/WORKFLOW.md`).

### Dostępne funkcje falowe (w `cam_common.scad`)

| Funkcja | Kształt | Typowe zastosowanie |
|---|---|---|
| `tri_wave(a, reps)` | trójkątna, symetryczna | zygzak, ściegi geometryczne |
| `sine_wave(a, reps)` | gładka sinusoida | fale, ściegi delikatne |
| `saw_wave(a, reps, skew)` | piła (asymetryczna, `skew` 0–1 steruje proporcją zbocza) | muszelka, ostre przejścia |
| `double_lobe(a, reps)` | fala podstawowa + druga harmoniczna | ozdobne, "podwójne" wzory |
| `diamond_lattice(a, reps)` | dwie przesunięte fale trójkątne | siatka rombów, plaster miodu |
| `feather(a, clusters)` | grupki drobnych wychyleń + większe przejście | piórko, ściegi grupowane |
| `arrow_sharpen(a, reps, skew)` | piła z wyostrzonymi szczytami | strzałka, ostre wzory |
| `pulse(a, reps, spike_w)` | płasko + pojedynczy impuls na cykl | ślepy ścieg, rzadkie "ugryzienia" |

Można je swobodnie łączyć: dodawanie (`f(a)+g(a)`), mnożenie amplitudy,
przesunięcie fazowe (`f(a+90)`), złożenie kąta (`f(2*a)` dla podwojonej
częstotliwości). `reps` to liczba powtórzeń wzoru na pełny obrót (360°) —
większe `reps` = gęstszy/węższy ścieg.

### Zasady projektowe

- **Amplituda ≤ 1.0** per funkcja (mnożnik na końcu, np. `* 0.8`) — wartości
  bliskie ±1 wykorzystują pełny zmierzony zakres ruchu czujnika; mniejsze
  dają węższy, bardziej subtelny ścieg.
- Pierwsza pozycja to zwyczajowo "zygzak referencyjny" (ciągłość z zestawem
  A, ułatwia porównanie/kalibrację po wydruku) — nie jest to wymóg techniczny,
  tylko konwencja przyjęta w B/C/D.
- Nie modyfikuj stałych mocowania (`BOSS0_R`, `NECK_*`, `SOCKET_*`,
  `THREAD_*`, `EDGE_MIN_R`/`EDGE_MAX_R`) w `cam_common.scad` dla pojedynczego
  bębna — to współdzielona geometria; zmiana tam wpłynie na WSZYSTKIE bębny.
  Jeśli naprawdę potrzebujesz innej geometrii mocowania (np. dla innego
  modelu maszyny), zrób osobną kopię `cam_common.scad`.

---

## EN

This project is meant to be a **generator**, not a closed set of three
patterns. The mounting geometry (flanges, thread, socket, spindle, the
sensor's allowed deflection range) lives entirely in
`tools/openscad/cam_common.scad` — every new drum automatically inherits the
correct, verified mechanical geometry. You only design **5 edge shapes**
(one per stitch position).

### Step by step

1. Copy [`tools/openscad/cam_template.scad`](../tools/openscad/cam_template.scad)
   to `models/generated/cam_<LETTER>.scad`.
2. Define 5 functions `func(a) = ...` — `a` is the rotation angle in degrees
   (0–360), the result is a value normalized to roughly `-1..1`.
   `cam_common.scad` rescales it to the real edge radius within the
   measured, safe range `[EDGE_MIN_R, EDGE_MAX_R]` (see `docs/DIMENSIONS.md`)
   — it is **not possible** to accidentally design a pattern that pushes the
   sensor beyond the mechanism's physical range.
3. Swap the letter in the `cam_with_grooves("X", [...])` call — this also
   controls the engraving on the flange.
4. Render: `openscad.exe -o cam_<LETTER>.stl cam_<LETTER>.scad` (see
   `docs/WORKFLOW.md`).

### Available wave functions (in `cam_common.scad`)

| Function | Shape | Typical use |
|---|---|---|
| `tri_wave(a, reps)` | symmetric triangle | zigzag, geometric stitches |
| `sine_wave(a, reps)` | smooth sine | waves, gentle stitches |
| `saw_wave(a, reps, skew)` | asymmetric sawtooth (`skew` 0–1 controls the slope ratio) | scallop, sharp transitions |
| `double_lobe(a, reps)` | base wave + second harmonic | decorative "double" patterns |
| `diamond_lattice(a, reps)` | two offset triangle waves | diamond lattice, honeycomb |
| `feather(a, clusters)` | small clustered wiggles + one bigger sweep | feather stitch, grouped stitches |
| `arrow_sharpen(a, reps, skew)` | sawtooth with sharpened peaks | arrowhead, sharp patterns |
| `pulse(a, reps, spike_w)` | flat baseline + one spike per cycle | blind hem, occasional "bites" |

Combine them freely: addition (`f(a)+g(a)`), amplitude scaling, phase shift
(`f(a+90)`), angle composition (`f(2*a)` for double frequency). `reps` is how
many times the pattern repeats per full rotation (360°) — a higher `reps`
means a denser/narrower stitch.

### Design rules

- **Amplitude ≤ 1.0** per function (the trailing multiplier, e.g. `* 0.8`) —
  values near ±1 use the full measured sensor travel range; smaller values
  give a narrower, more subtle stitch.
- Position 1 is conventionally a "reference zigzag" (continuity with set A,
  makes post-print comparison/calibration easier) — that's a convention
  followed by B/C/D, not a technical requirement.
- Don't modify the mounting constants (`BOSS0_R`, `NECK_*`, `SOCKET_*`,
  `THREAD_*`, `EDGE_MIN_R`/`EDGE_MAX_R`) in `cam_common.scad` for a single
  drum — that's shared geometry; changing it there affects EVERY drum. If you
  genuinely need different mounting geometry (e.g. for a different machine
  model), make a separate copy of `cam_common.scad`.

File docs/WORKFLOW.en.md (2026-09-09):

# Workflow

*(Polish original: [`WORKFLOW.md`](WORKFLOW.md))*

## Requirements

- OpenSCAD **2021.01 or newer** (the files use function literals: `function(a) ...`).
  This machine has `C:\Program Files\OpenSCAD\openscad.exe` (2021.01.22) installed.

## Rendering

```powershell
& "C:\Program Files\OpenSCAD\openscad.exe" -o cam_A.stl models\generated\cam_A.scad
& "C:\Program Files\OpenSCAD\openscad.exe" -o cam_B.stl models\generated\cam_B.scad
& "C:\Program Files\OpenSCAD\openscad.exe" -o cam_C.stl models\generated\cam_C.scad
& "C:\Program Files\OpenSCAD\openscad.exe" -o cam_D.stl models\generated\cam_D.scad
& "C:\Program Files\OpenSCAD\openscad.exe" -o mating_shaft_reference.stl tools\openscad\mating_shaft_reference.scad
```

Each stitch position is a single `linear_extrude` of a polygon (the edge profile) — fast. The
thread on the flange (`boss0_threaded()`) is a helix built from many `hull()` operations
between spheres — slower. Overall: about 1.5 minutes per drum file, a fraction of a second for
`mating_shaft_reference` (no thread/teeth).

To see just the profile shape (a cross-section), e.g. for a quick check after changing a
pattern:

```powershell
& "C:\Program Files\OpenSCAD\openscad.exe" -o cross.png --render `
  --camera=0,0,13,0,0,0,55 --projection=o tools\openscad\render\cam_B_cross.scad
```

(`projection(cut=true)` in these files makes a cross-section at Z=13 — the barrel's midpoint.)

## Order of work

1. Print `tools/openscad/mating_shaft_reference.scad` and check the fit of the hole + prismatic
   key against the machine's socket — a faster, cheaper test than a whole drum (see
   `docs/PRINTABILITY.en.md`).
2. Print a test copy of set A (the native `cam_A.scad`, or the reference file from
   `models/original/`) and check the fit against the machine — confirms the measured/
   photographed dimensions in `docs/DIMENSIONS.en.md` are correct.
3. Print a test copy of one position of set B/C/D and compare the stitch width against set A —
   calibrate `EDGE_MAX_R` / `EDGE_MIN_R` in `cam_common.scad` if needed (see
   `docs/PRINTABILITY.en.md` for the rationale behind the current values and safety margins).
4. After calibration, print the full B, C, D sets — or design your own, see
   [`docs/CREATING_NEW_DRUMS.md`](CREATING_NEW_DRUMS.md).
5. Update the status in the table in `README.md` to "tested" once physically verified.

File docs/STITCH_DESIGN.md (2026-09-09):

# Wzory ściegów — zestawy fabryczne A1, B1, C1 oraz zestaw rozszerzony D

## Źródła historyczne i specyfikacja fabryczna

Geometria i wzory ściegów zostały zrekonstruowane w oparciu o oficjalne dokumenty techniczne producenta:
1. **Instrukcja obsługi Husqvarna Automatic 21 E** (`Husqvarna-21E_User-Manual_NO.pdf`):
   - Strona 31: *Grunnmönster for kammene A1, B1 og C1* — oficjalna tabela parametrów (szerokość, długość) oraz ryciny przeszyć,
   - Strona 25: *Mönsternøkkelen* — tarcza wyboru ściegów 1- i 2-igłowych,
   - Strona 27, 29, 30: numery katalogowe, procedura wymiany bębna na pozycji 5,
   - Strona 55: wykaz części i akcesoriów.
2. **Instrukcja serwisowa Viking Automatic class 21** (`Husqvarna-Class-21_Service-Manual_EN.pdf`):
   - Sekcja 1 (str. 1): kalibracja minimalnego luzu wodzika (*follower*) w najwyższym punkcie krzywki (`EDGE_MAX_R = 17.03 mm`) na **pozycji 5**,
   - Sekcja 2 (str. 1): synchronizacja fazowa igły — ruch poprzeczny igielnicy kończy się, gdy czubek igły jest co najmniej 7 mm nad płytką ściegową (uzasadnienie faz stabilizacji *dwell* w profilach trapezowych).

---

## Zasada działania mechanizmu

Każdy bęben posiada **5 pozycji osiowych** (`N_POS = 5`), rozdzielonych na odcinku $Z \in [6.4, 23.6]\text{ mm}$ (długość ścieżki `BAND_LEN = 3.44 mm`).
Dźwignia wyboru ściegu (*Mönstervelger*, pozycje 1–5 na tarczy czołowej maszyny) przesuwa palec wodzika wzdłuż osi wałka bębna.
Palec wodzika spoczywa bezpośrednio na profilowanej krawędzi obwodowej walca:
* Gdy krawędź ma promień maksymalny (`EDGE_MAX_R = 17.03 mm`, wartość znormalizowana `-1`), igielnica znajduje się w skrajnym lewym położeniu (baza ściegu prostego).
* Gdy krawędź opada do dna doliny (`EDGE_MIN_R = 14.20 mm`, wartość znormalizowana `+1`), igielnica wykonuje maksymalne wychylenie w prawo (amplituda radialna zęba `EDGE_SWING = 2.83 mm`).

---

## Zestaw A1 — Bęben standardowy (`S 41-10950`)

Fabryczny bęben dostarczany w maszynie (*„i maskinen”*). Zapewnia podstawowe ściegi użytkowe i elastyczne.

| Poz. | Nazwa ściegu wg instrukcji | Nastawa fabryczna (szer./dł.) | Funkcja matematyczna | Zastosowanie i charakterystyka |
|:---:|:---|:---:|:---|:---|
| **1** | **Ścieg brzegowy / kryty** (*Usynlig faldsöm / Picot*) | 4 / 0.3 | `blind_hem(a, 3, 0.20)` | 4–5 wkłuć prostych po lewej stronie + pojedynczy skok w prawo do podszywania dołów i krycia brzegów. |
| **2** | **Zygzak 3-stopniowy elastyczny** (*Trestings siksak / Quick-Stopp*) | 4 / 0.3 | `three_step_zigzag(a, 3)` | Trójskok (3 wkłucia w lewo, 3 w prawo) — elastyczne łączenie dzianin, wszywanie gumy, cerowanie. |
| **3** | **Zygzak klasyczny szeroki** | 4 / 1.0 | `trap_wave(a, 9, 0.28) * 0.95` | Wydłużony skok zygzaka do obrzucania krawędzi. |
| **4** | **Ścieg cerujący / ozdobny gęsty** | 4 / 0.3 | `trap_wave(a, 9, 0.28) * 0.80` | Gęsty zygzak satynowy. |
| **5** | **Zygzak standardowy referencyjny** | 4 / 1.5 | `trap_wave(a, 9, 0.28) * 0.95` | Pozycja spoczynkowa mechanizmu, baza do wymiany bębna. |

---

## Zestaw B1 — Bęben akcesoryjny (`S 41-10951`)

Zestaw ściegów ozdobnych i falistych.

| Poz. | Nazwa ściegu wg instrukcji | Nastawa fabryczna (szer./dł.) | Funkcja matematyczna | Zastosowanie i charakterystyka |
|:---:|:---|:---:|:---|:---|
| **1** | **Ścieg serpentynowy / fala płynna** (*Slangesöm*) | 4 / 1.5 | `sine_wave(a, 3) * 0.90` | Płynna sinusoida o łagodnych łukach (ozdabianie falbanek, bielizny). |
| **2** | **Jodełka schodkowa / gęsta fala łamana** | 4 / 0.3 | `tri_wave(a, 3)*0.70 + tri_wave(a, 18)*0.25` | Załamana fala z drobnym ząbkiem krawędziowym. |
| **3** | **Satynowy romb / liście / perełki** (*Diamantsöm*) | 4 / 0.3 | `diamond_satin(a, 18, 3)` | Płynne rozszerzanie i zwężanie szerokości satyny tworzące serię rombów/perełek. |
| **4** | **Ząbki skośne / piła** (*Tannsöm*) | 4 / 0.3 | `saw_wave(a, 6, 0.80) * 0.90` | Asymetryczny profil piłokształtny o ostrym powrocie. |
| **5** | **Zygzak standardowy referencyjny** | 4 / 1.5 | `trap_wave(a, 9, 0.28) * 0.95` | Pozycja spoczynkowa i referencyjna (identyczna we wszystkich bębnach). |

---

## Zestaw C1 — Bęben akcesoryjny (`S 41-10952`)

Zestaw ściegów geometrycznych i meandrowych.

| Poz. | Nazwa ściegu wg instrukcji | Nastawa fabryczna (szer./dł.) | Funkcja matematyczna | Zastosowanie i charakterystyka |
|:---:|:---|:---:|:---|:---|
| **1** | **Meander grecki / baszty** (*Mekaniskt meander / Tinn*) | 4 / 0.3 | `trap_wave(a, 4, 0.45) * 0.90` | Prostopadłe uskoki z gęstym kryciem tworzące grzebień meandrowy. |
| **2** | **Ścieg płomieniowy / ostry trójkątny** (*Flammesöm*) | 4 / 0.3 | `arrow_sharpen(a, 6, 0.50) * 0.90` | Wyostrzone zęby trójkątne o dużej dynamice wizualnej. |
| **3** | **Bloki satynowe prostokątne** (*Blokksöm*) | 4 / 0.3 | `block_satin(a, 16, 4)` | Naprzemienne schodkowe prostokąty satynowe (przeskok lewo-prawo). |
| **4** | **Klepsydra / podwójny romb** | 4 / 0.3 | `hourglass_satin(a, 18, 3)` | Symetryczne przewężenie satyny tworzące wzór klepsydry. |
| **5** | **Zygzak standardowy referencyjny** | 4 / 1.5 | `trap_wave(a, 9, 0.28) * 0.95` | Pozycja spoczynkowa i referencyjna. |

---

## Zestaw D — Rozszerzony / Eksperymentalny

Zestaw autorski przeznaczony do zadań specjalnych i ściegów wzmocnionych.

| Poz. | Nazwa ściegu | Nastawa (szer./dł.) | Funkcja matematyczna | Charakterystyka |
|:---:|:---|:---:|:---|:---|
| **1** | **Zygzak wąski referencyjny** | 2 / 1.0 | `tri_wave(a, 10) * 0.40` | Drobny zygzak precyzyjny. |
| **2** | **Ślepy ścieg wzmocniony** | 4 / 0.5 | `blind_hem(a, 4, 0.15)` | Rzadsze wkłucia poprzeczne. |
| **3** | **Drabinka** | 4 / 0.5 | `sign(sine_wave(a, 6)) * 0.85` | Dwie równoległe szyny z szybkim przeskokiem. |
| **4** | **Potrójny prosty elastyczny** | 1 / 1.5 | `tri_wave(a, 18) * 0.30` | Szybka mikro-oscylacja wzmacniająca szew. |
| **5** | **Zygzak standardowy referencyjny** | 4 / 1.5 | `trap_wave(a, 9, 0.28) * 0.95` | Pozycja spoczynkowa. |

---

## Zasady mechaniczne i serwisowe

1. **Pozycja nr 5 jako stan spoczynkowy:**
   Na każdym bębnie pozycja nr 5 to standardowy zygzak trapezowy. Zgodnie z instrukcją obsługi (str. 28/30), **przed demontażem lub montażem bębna należy zawsze ustawić wybierak ściegów na pozycję 5**.
2. **Kalibracja zerowego luzu:**
   Zgodnie z instrukcją serwisową (sekcja 1, str. 1), przy ściegu prostym (nastawa 0 na ramieniu i pozycja 5 na wybieraku) luz między wierzchołkiem zęba (`EDGE_MAX_R = 17.03 mm`) a palcem wodzika powinien być zredukowany do absolutnego minimum.
3. **Zakaz pracy bez bębna (*OBS!*, str. 31):**
   Nigdy nie należy uruchamiać maszyny z wyjętym bębnem ściegowym.

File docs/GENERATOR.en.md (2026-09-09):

# Husqvarna 21E Stitch Drum Generator User Guide

This project includes a universal, parametric stitch drum generation system featuring a built-in catalog of over 35 pre-verified patterns (utility, stretch, decorative waves, modulated satin, meanders, and geometric checkerboards).

---

## 🌐 Online Web Generator in Browser (Recommended for Everyone!)

> [!TIP]
> **No installation required (no OpenSCAD or technical tools needed)!**
> Launch the generator directly in your browser:
> 👉 **[https://qbarteczek.github.io/husqvarna-viking-21a-cams/](https://qbarteczek.github.io/husqvarna-viking-21a-cams/)**

The application runs 100% in your browser (desktop or mobile) and lets you design custom stitch drums and immediately download a 3D-printable `.stl` file in a fraction of a second.

---

## 3 Ways to Use the Generator

### Method 1: Web Application Online / Local (Easiest for Sewing Machine Users)

1. **How to open:**
   * **Online (recommended):** Go to [https://qbarteczek.github.io/husqvarna-viking-21a-cams/](https://qbarteczek.github.io/husqvarna-viking-21a-cams/)
   * **Offline:** Double-click `Uruchom_Generator.bat` in the project root directory (or open `index.html`).
2. **Key Features:**
   * **Real-time 3D Drum Model (WebGL / Three.js):** Rotate, zoom, and inspect the drum geometry with actual teeth profiles, grooves, and mounting keyway in real-time. No waiting 30–40 seconds for CSG renders as in OpenSCAD!
   * **Live Fabric Simulation:** Visual thread stitching across all 5 positions.
   * **Historical Presets:** 1-click loading for factory sets `A1`, `B1`, `C1`, and `D`.
   * **36 Decorative Stitches:** Categorized, searchable library.
3. **Customize:** Click any slot (1–5), then click any stitch card to assign it.
4. **Direct 3D Print Export:**
   * Click the green button **„💾 Pobierz gotowy plik STL do druku 3D”** to instantly download a clean, watertight (2-manifold) `.stl` file ready for slicing in Bambu Studio, PrusaSlicer, Cura, or OrcaSlicer!
   * Optionally download the `.scad` script if you wish to archive the parametric code.

---

### Method 2: OpenSCAD Customizer GUI (Desktop Users)

---

### Method 3: PowerShell CLI Batch Generator (`tools/generator/generate_drum.ps1`)

Automated script for headless generation and compilation:
```powershell
.\tools\generator\generate_drum.ps1 -Letter "E" -Pos1 1 -Pos2 14 -Pos3 23 -Pos4 29 -Pos5 4 -ExportSTL
```
The resulting `cam_E.stl` will be generated in `models/generated/`.

---

## Complete Stitch Catalog Reference (`stitch_catalog.scad`)

| ID | Key | Pattern Name | Category | Factory Source |
|:---:|:---|:---|:---:|:---:|
| **0** | `straight` | Straight Stitch | Utility | — |
| **1** | `blind_hem_std` | Blind Hem Standard | Utility | A1 (pos. 1) |
| **2** | `blind_hem_dense` | Blind Hem Dense (4c) | Utility | — |
| **3** | `blind_hem_wide` | Blind Hem Wide | Utility | — |
| **4** | `zigzag_std` | Standard Reference Zigzag | Utility | A1/B1/C1 (pos. 5) |
| **5** | `zigzag_wide` | Wide Zigzag | Utility | A1 (pos. 3) |
| **6** | `zigzag_narrow` | Narrow Precision Zigzag | Utility | — |
| **7** | `zigzag_satin` | Dense Darning Satin | Utility | A1 (pos. 4) |
| **8** | `three_step_elastic` | 3-Step Elastic Zigzag | Utility | A1 (pos. 2) |
| **9** | `four_step_elastic` | 4-Step Super Stretch | Utility | — |
| **10** | `overlock_open` | Open Stretch Overlock | Utility | — |
| **11** | `overlock_closed` | Closed Elastic Overlock | Utility | — |
| **12** | `triple_stretch` | Triple Stretch Straight | Utility | — |
| **13** | `ladder` | Ladder / Darning Stitch | Utility | — |
| **14** | `serpentine_wide` | Wide Serpentine Wave (3c) | Decorative | B1 (pos. 1) |
| **15** | `serpentine_med` | Medium Serpentine Wave (4c) | Decorative | — |
| **16** | `serpentine_dense` | Dense Serpentine Wave (6c) | Decorative | — |
| **17** | `scallop_wave` | Scallop / Shell Wave | Decorative | — |
| **18** | `double_lobe` | Double Lobe Wave | Decorative | — |
| **19** | `feather` | Feather Stitch | Decorative | — |
| **20** | `stepped_chevron` | Stepped Chevron Wave | Decorative | B1 (pos. 2) |
| **21** | `angled_teeth` | Angled Teeth / Saw | Decorative | B1 (pos. 4) |
| **22** | `fine_comb` | Fine Comb Wave (14c) | Decorative | — |
| **23** | `diamond_satin_3` | Diamond Satin Leaf (3c) | Satin | B1 (pos. 3) |
| **24** | `diamond_satin_4` | Dense Diamond Satin (4c) | Satin | — |
| **25** | `pearl_beads` | Pearl Beads Satin | Satin | — |
| **26** | `hourglass_satin` | Hourglass Satin | Satin | C1 (pos. 4) |
| **27** | `flame_satin` | Flame Satin | Satin | C1 (pos. 2) |
| **28** | `taper_satin` | Tapering Satin Wedge | Satin | — |
| **29** | `greek_key_4` | Greek Key Meander (4c) | Geometric | C1 (pos. 1) |
| **30** | `greek_key_5` | Greek Key Meander (5c) | Geometric | — |
| **31** | `satin_blocks` | Alternating Satin Blocks | Geometric | C1 (pos. 3) |
| **32** | `checker_step` | Checkerboard Step | Geometric | — |
| **33** | `cross_stitch` | Geometric Cross Stitch | Geometric | — |
| **34** | `arrowhead` | Sharp Arrowhead | Geometric | — |
| **35** | `honeycomb` | Honeycomb Lattice | Geometric | — |

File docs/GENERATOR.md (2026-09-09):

# Instrukcja obsługi generatora bębnów ściegowych Husqvarna 21E

Projekt zawiera wbudowany, uniwersalny system generowania własnych bębnów ściegowych z katalogu ponad 35 predefiniowanych wzorców (ściegi użytkowe, elastyczne, ozdobne fale, satynowe romby, meandry i szachownice).

---

## 🌐 Generator Online w Przeglądarce (Zalecany dla każdego użytkownika!)

> [!TIP]
> **Nie musisz instalować żadnego programu (w tym OpenSCAD)!**
> Wejdź bezpośrednio na stronę generatora:
> 👉 **[https://qbarteczek.github.io/husqvarna-viking-21a-cams/](https://qbarteczek.github.io/husqvarna-viking-21a-cams/)**

Aplikacja działa w 100% w przeglądarce internetowej (na komputerze lub telefonie) i umożliwia wygenerowanie oraz natychmiastowe pobranie gotowego pliku `.stl` do druku 3D w ułamku sekundy.

---

## 3 Sposoby korzystania z generatora

### Sposób 1: Aplikacja Webowa Online / Lokalna (Najprostszy dla amatorów!)

1. **Uruchomienie:**
   * **Online (zalecane):** Otwórz [https://qbarteczek.github.io/husqvarna-viking-21a-cams/](https://qbarteczek.github.io/husqvarna-viking-21a-cams/)
   * **Lokalnie bez internetu:** Kliknij dwukrotnie plik `Uruchom_Generator.bat` w głównym katalogu projektu (lub otwórz `index.html`).
2. **Możliwości aplikacji:**
   * **Błyskawiczny podgląd 3D bębna (WebGL / Three.js):** obracaj myszką, powiększaj i oglądaj rzeczywisty bęben z ząbkami, rowkami i wpustem montażowym. Każda zmiana ściegu jest widoczna w czasie rzeczywistym (0 sekund oczekiwania, brak długiego renderowania jak w OpenSCAD).
   * **Wirtualny haft na tkaninie:** dynamiczna symulacja przeszycia igłą nici w kolorze dla wszystkich 5 pozycji.
   * **Gotowe presety:** 1-kliknięciem załaduj historyczny zestaw `A1`, `B1`, `C1` lub `D`.
   * **Katalog 36 ściegów ozdobnych:** podzielony na kategorie (użytkowe, elastyczne, fale, satynowe, meandry) z natychmiastowym wyszukiwaniem.
3. **Wybór ściegów:** Kliknij wybraną pozycję (1–5) na górnym pasku, a następnie kliknij dowolny ścieg z katalogu.
4. **Pobranie pliku do druku 3D:**
   * Kliknij zielony przycisk **„💾 Pobierz gotowy plik STL do druku 3D”** – w ciągu 0.01 s otrzymujesz gotowy, zamknięty (watertight / 2-manifold) plik `cam_X.stl`, który możesz bezpośrednio otworzyć w Cura, PrusaSlicer, Bambu Studio czy OrcaSlicer i puścić na drukarkę 3D!
   * Opcjonalnie: możesz też pobrać kod `.scad`, jeśli chcesz go zachować w bibliotece OpenSCAD.

---

### Sposób 2: W programie OpenSCAD (Panel okienkowy Customizer GUI)

Dla użytkowników pracujących bezpośrednio w OpenSCAD:
1. Zainstaluj darmowy program [OpenSCAD](https://openscad.org/) (wersja 2021.01+).
2. Otwórz plik [`tools/openscad/cam_generator.scad`](../tools/openscad/cam_generator.scad).
3. W górnym menu włącz panel parametrów: **Window -> Customizer** (lub odznacz *Hide Customizer*).
4. Wybierz preset (`A1`, `B1`, `C1`, `D`) lub tryb `Custom` i wybierz ściegi dla pozycji 1–5.
5. Wciśnij klawisz **F6** (Render), a po zakończeniu obliczeń **F7** (Export as STL).

---

### Sposób 3: Wiersz poleceń PowerShell (`tools/generator/generate_drum.ps1`)

Automatyczne generowanie kodu i natychmiastowa kompilacja siatki STL:
```powershell
# Wygenerowanie pliku .scad i kompilacja do .stl:
.\tools\generator\generate_drum.ps1 -Letter "E" -Pos1 1 -Pos2 14 -Pos3 23 -Pos4 29 -Pos5 4 -ExportSTL
```
Wynikowy plik `cam_E.stl` zostanie zapisany w katalogu `models/generated/`.

---

## Pełny wykaz ściegów w katalogu (`stitch_catalog.scad`)

| ID | Klucz | Nazwa ściegu | Kategoria | Źródło fabryczne |
|:---:|:---|:---|:---:|:---:|
| **0** | `straight` | Ścieg prosty zerowy | Użytkowy | — |
| **1** | `blind_hem_std` | Ścieg kryty standardowy | Użytkowy | A1 (poz. 1) |
| **2** | `blind_hem_dense` | Ścieg kryty gęsty (4c) | Użytkowy | — |
| **3** | `blind_hem_wide` | Ścieg kryty szeroki | Użytkowy | — |
| **4** | `zigzag_std` | Zygzak standardowy referencyjny | Użytkowy | A1/B1/C1 (poz. 5) |
| **5** | `zigzag_wide` | Zygzak szeroki | Użytkowy | A1 (poz. 3) |
| **6** | `zigzag_narrow` | Zygzak wąski precyzyjny | Użytkowy | — |
| **7** | `zigzag_satin` | Zygzak gęsty satynowy | Użytkowy | A1 (poz. 4) |
| **8** | `three_step_elastic` | Trójskok elastyczny | Użytkowy | A1 (poz. 2) |
| **9** | `four_step_elastic` | Zygzak 4-stopniowy superelastyczny | Użytkowy | — |
| **10** | `overlock_open` | Ścieg owerlokowy otwarty | Użytkowy | — |
| **11** | `overlock_closed` | Ścieg owerlokowy zamknięty | Użytkowy | — |
| **12** | `triple_stretch` | Potrójny prosty elastyczny | Użytkowy | — |
| **13** | `ladder` | Ścieg drabinkowy / cerujący | Użytkowy | — |
| **14** | `serpentine_wide` | Serpentyna szeroka (3c) | Ozdobny | B1 (poz. 1) |
| **15** | `serpentine_med` | Serpentyna średnia (4c) | Ozdobny | — |
| **16** | `serpentine_dense` | Serpentyna gęsta (6c) | Ozdobny | — |
| **17** | `scallop_wave` | Muszelka / łuska asymetryczna | Ozdobny | — |
| **18** | `double_lobe` | Podwójna pętla / podwójna fala | Ozdobny | — |
| **19** | `feather` | Piórko gałązkowe | Ozdobny | — |
| **20** | `stepped_chevron` | Jodełka schodkowa z ząbkiem | Ozdobny | B1 (poz. 2) |
| **21** | `angled_teeth` | Ząbki skośne / piła | Ozdobny | B1 (poz. 4) |
| **22** | `fine_comb` | Grzebyk drobny (14c) | Ozdobny | — |
| **23** | `diamond_satin_3` | Satynowy romb / liść (3c) | Satynowy | B1 (poz. 3) |
| **24** | `diamond_satin_4` | Satynowy romb gęsty (4c) | Satynowy | — |
| **25** | `pearl_beads` | Perełki satynowe okrągłe | Satynowy | — |
| **26** | `hourglass_satin` | Klepsydra satynowa | Satynowy | C1 (poz. 4) |
| **27** | `flame_satin` | Płomienie satynowe | Satynowy | C1 (poz. 2) |
| **28** | `taper_satin` | Stożek satynowy rosnący | Satynowy | — |
| **29** | `greek_key_4` | Grecki klucz meander (4c) | Geometryczny | C1 (poz. 1) |
| **30** | `greek_key_5` | Grecki klucz gęsty (5c) | Geometryczny | — |
| **31** | `satin_blocks` | Bloki satynowe naprzemienne | Geometryczny | C1 (poz. 3) |
| **32** | `checker_step` | Szachownica schodkowa | Geometryczny | — |
| **33** | `cross_stitch` | Krzyżyki geometryczne | Geometryczny | — |
| **34** | `arrowhead` | Strzałka ostra wyostrzona | Geometryczny | — |
| **35** | `honeycomb` | Plaster miodu / siatka rombowa | Geometryczny | — |

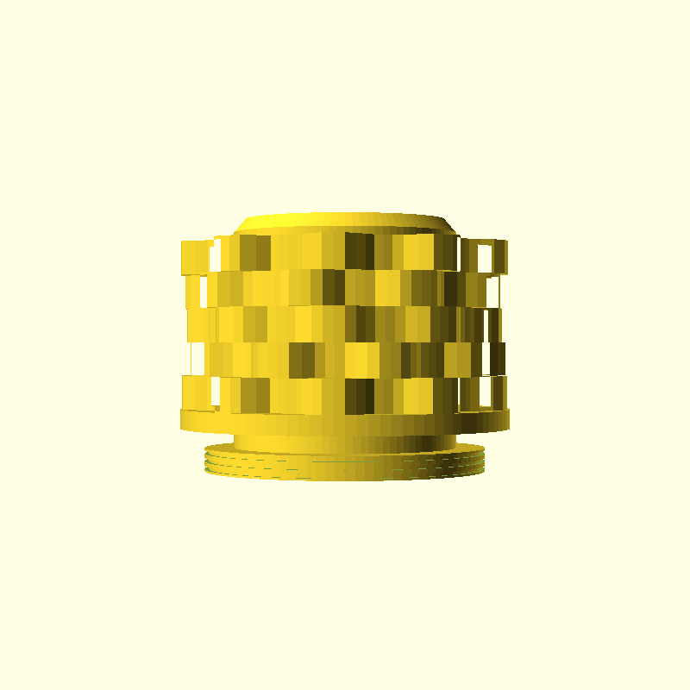
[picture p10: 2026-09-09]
docs/renders/cam_A_side.png

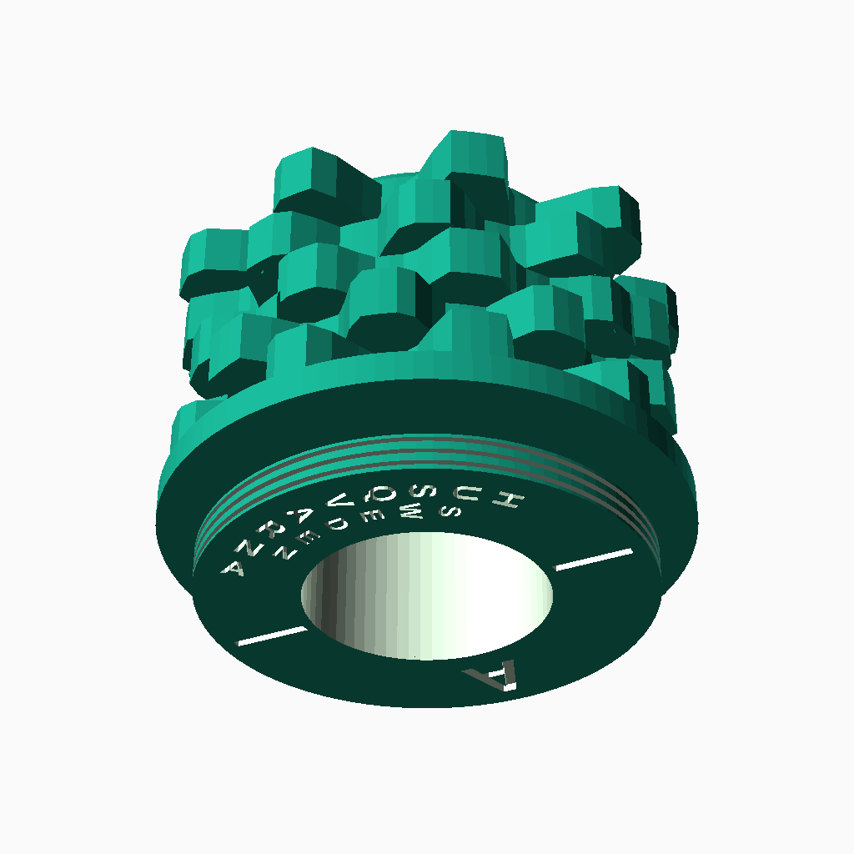
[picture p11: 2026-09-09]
docs/renders/cam_A_front_angle.png

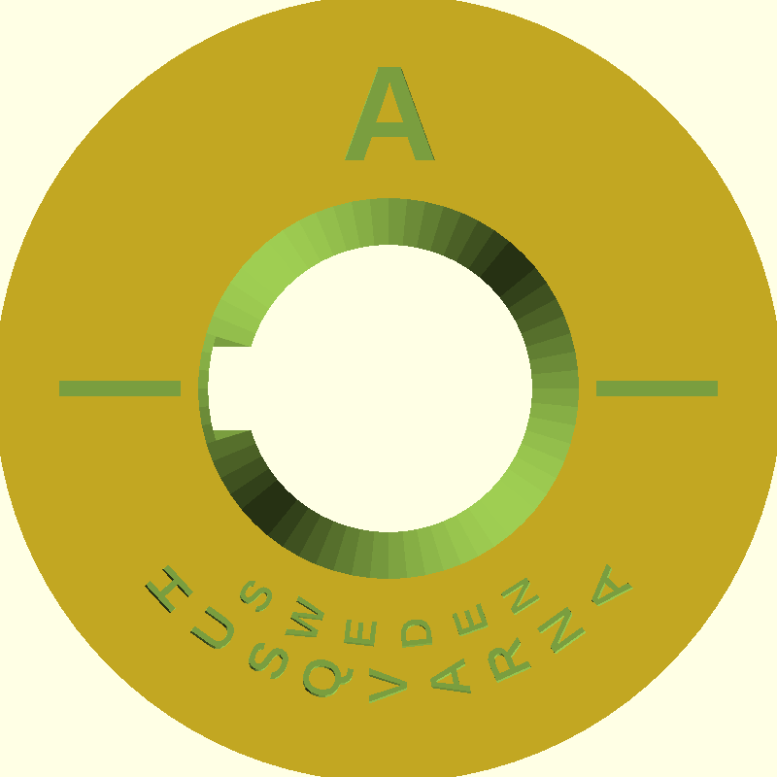
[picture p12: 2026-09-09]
docs/renders/cam_A_front_check.png

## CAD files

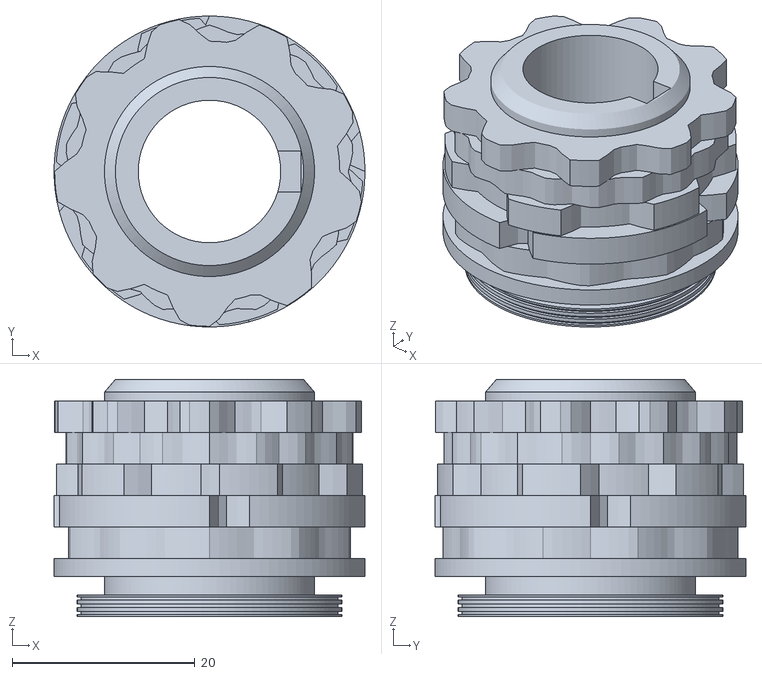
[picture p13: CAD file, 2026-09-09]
models/generated/cam_D.stl
34.1 x 34.1 x 26.0

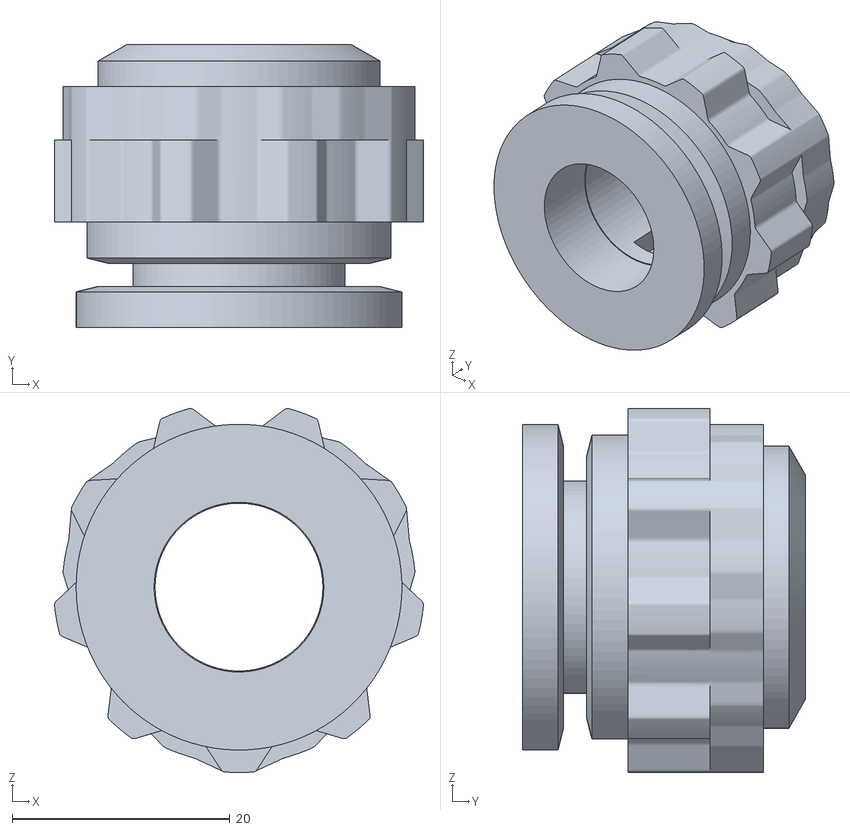
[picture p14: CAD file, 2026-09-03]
models/original/cam_A_V21ZZ3Z.stl
33.9 x 26.0 x 33.4

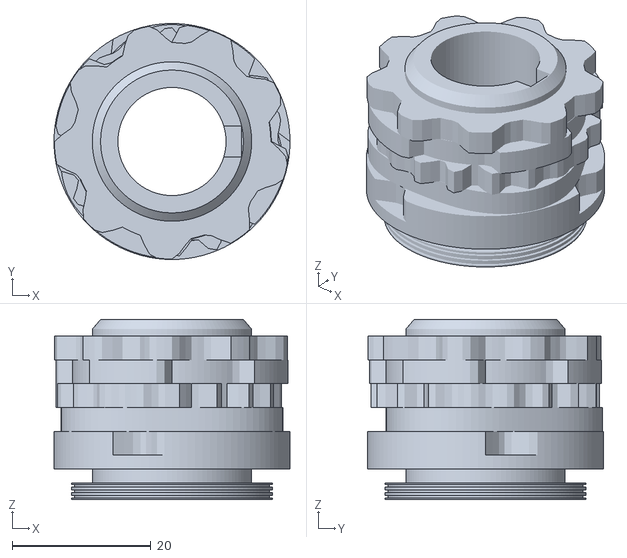
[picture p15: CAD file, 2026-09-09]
models/generated/cam_E.stl
34.1 x 34.1 x 26.0

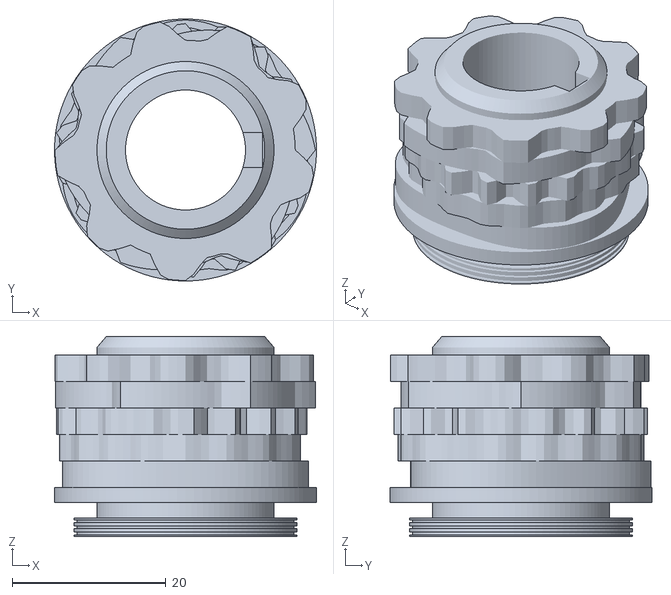
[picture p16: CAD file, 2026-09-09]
models/generated/cam_B.stl
34.1 x 34.1 x 26.0

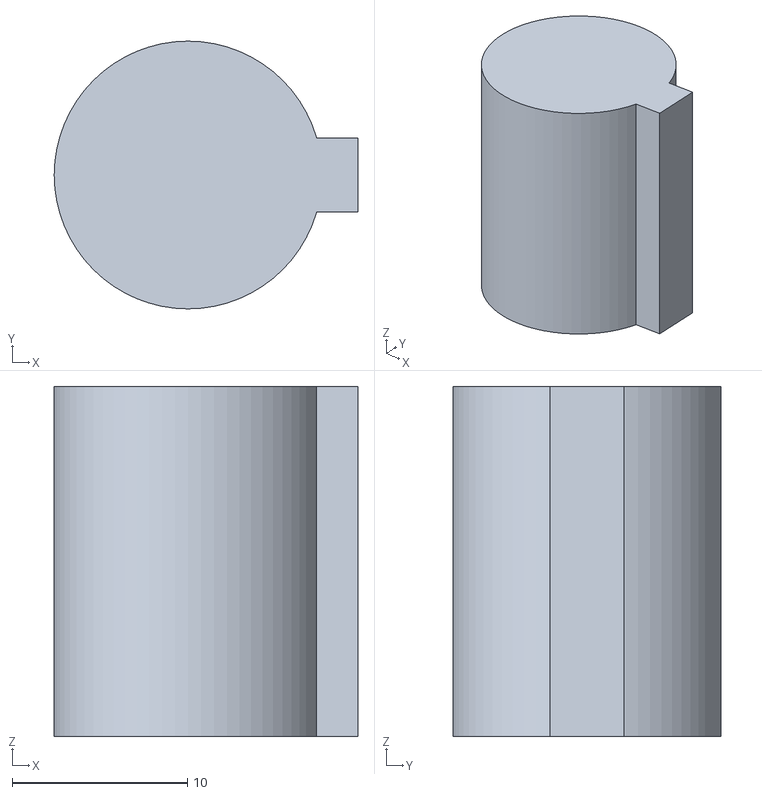
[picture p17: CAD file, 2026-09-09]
models/generated/mating_shaft_reference.stl
17.4 x 15.3 x 20.0

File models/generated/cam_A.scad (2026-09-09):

// Bęben A1 (standardowy, nr kat. S 41-10950) dla Husqvarna 21E / 21A.
// Odtworzenie fabrycznych ściegów z instrukcji obsługi Husqvarna 21E (str. 31):
// Poz 1: Ścieg kryty / brzegowy (usynlig faldsöm / picot, stinglengde 0.3)
// Poz 2: Zygzak 3-stopniowy elastyczny (trestings siksak, stinglengde 0.3)
// Poz 3: Zygzak szeroki (stinglengde 1.0)
// Poz 4: Zygzak gęsty cerujący (stinglengde 0.3)
// Poz 5: Zygzak standardowy referencyjny / stan spoczynkowy (stinglengde 1.5)
include <../../tools/openscad/cam_common.scad>

function a_pos1(a) = blind_hem(a, 3, 0.20);
function a_pos2(a) = three_step_zigzag(a, 3);
function a_pos3(a) = trap_wave(a, 9, 0.28) * 0.95;
function a_pos4(a) = trap_wave(a, 9, 0.28) * 0.80;
function a_pos5(a) = trap_wave(a, 9, 0.28) * 0.95;

cam_with_grooves("A", [
    function(a) a_pos1(a),
    function(a) a_pos2(a),
    function(a) a_pos3(a),
    function(a) a_pos4(a),
    function(a) a_pos5(a),
]);

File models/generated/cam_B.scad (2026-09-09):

// Bęben B1 (mönsterkamsats B:1, nr kat. S 41-10951) dla Husqvarna 21E / 21A.
// Odtworzenie fabrycznych ściegów z instrukcji obsługi Husqvarna 21E (str. 31):
// Poz 1: Ścieg serpentynowy / fala płynna (slangesöm, stinglengde 1.5)
// Poz 2: Jodełka schodkowa / gęsta fala łamana (stinglengde 0.3)
// Poz 3: Satynowy romb / perełki / liście (diamantsöm, stinglengde 0.3)
// Poz 4: Ząbki skośne / piła (tannsöm, stinglengde 0.3)
// Poz 5: Zygzak standardowy referencyjny (stinglengde 1.5)
include <../../tools/openscad/cam_common.scad>

function b_pos1(a) = sine_wave(a, 3) * 0.90;
function b_pos2(a) = (tri_wave(a, 3) * 0.70 + tri_wave(a, 18) * 0.25);
function b_pos3(a) = diamond_satin(a, 18, 3);
function b_pos4(a) = saw_wave(a, 6, 0.80) * 0.90;
function b_pos5(a) = trap_wave(a, 9, 0.28) * 0.95;

cam_with_grooves("B", [
    function(a) b_pos1(a),
    function(a) b_pos2(a),
    function(a) b_pos3(a),
    function(a) b_pos4(a),
    function(a) b_pos5(a),
]);

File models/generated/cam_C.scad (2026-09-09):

// Bęben C1 (mönsterkamsats C:1, nr kat. S 41-10952) dla Husqvarna 21E / 21A.
// Odtworzenie fabrycznych ściegów z instrukcji obsługi Husqvarna 21E (str. 31):
// Poz 1: Meander grecki / baszty (mekaniskt meander, stinglengde 0.3)
// Poz 2: Ścieg płomieniowy / ostry trójkątny (flammesöm, stinglengde 0.3)
// Poz 3: Bloki satynowe prostokątne (blokksöm, stinglengde 0.3)
// Poz 4: Klepsydra / podwójny romb (stinglengde 0.3)
// Poz 5: Zygzak standardowy referencyjny (stinglengde 1.5)
include <../../tools/openscad/cam_common.scad>

function c_pos1(a) = trap_wave(a, 4, 0.45) * 0.90;
function c_pos2(a) = arrow_sharpen(a, 6, 0.50) * 0.90;
function c_pos3(a) = block_satin(a, 16, 4);
function c_pos4(a) = hourglass_satin(a, 18, 3);
function c_pos5(a) = trap_wave(a, 9, 0.28) * 0.95;

cam_with_grooves("C", [
    function(a) c_pos1(a),
    function(a) c_pos2(a),
    function(a) c_pos3(a),
    function(a) c_pos4(a),
    function(a) c_pos5(a),
]);

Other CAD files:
models/generated/cam_C.stl
models/generated/cam_A.stl
models/generated/cam_D.scad
models/generated/cam_E.scad
tools/openscad/cam_common.scad
tools/openscad/cam_generator.scad
tools/openscad/cam_template.scad
tools/openscad/mating_shaft_reference.scad
tools/openscad/render/assembly_view.scad
tools/openscad/render/cam_A_cross.scad
tools/openscad/render/cam_A_view.scad
tools/openscad/render/cam_B_cross.scad
tools/openscad/render/cam_B_view.scad
tools/openscad/render/cam_C_cross.scad
tools/openscad/render/cam_C_view.scad
tools/openscad/render/cam_D_cross.scad
tools/openscad/render/cam_D_view.scad
tools/openscad/stitch_catalog.scad
tools/openscad/test_text.scad

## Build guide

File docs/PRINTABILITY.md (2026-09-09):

# Analiza drukowalności i zalecenia druku 3D dla bębnów Husqvarna 21E

## Status weryfikacji geometrii

Wszystkie modele w formacie STL wygenerowano przy użyciu pełnego silnika CGAL w OpenSCAD:

```
Simple: yes
Volumes: 3
```

Wynik `Simple: yes` gwarantuje, że bryły są w 100% zamkniętymi, poprawnymi rozmaitościami 2-manifold (watertight/manifold), wolnymi od samoprzecięć czy odwróconych normalnych, gotowymi bezpośrednio do wczytania w dowolnym slicerze (Bambu Studio, PrusaSlicer, Cura, OrcaSlicer).

---

## Podsumowanie geometrii zgodnej z fizycznym bębnem

1. **Orientacja bębna do druku**:
   - **Oś Z pionowo**, czoło bębna (dysk z grawerunkiem Z=0) spoczywa płasko na stole roboczym (build plate).
   - Taka orientacja gwarantuje:
     - Maksymalną dokładność wymiarową profilu zębów krzywki w płaszczyźnie XY (rozdzielczość pasów i silników osi XY zamiast skoków warstwy Z).
     - Idealnie okrągły otwór centralny oraz rowek wpustowy bez konieczności podpór wewnątrz otworu.
     - Rowki na dysku czołowym układają się poziomo, nie tworząc nawisów.
     - Kołnierz tylny ze stożkową fazą drukuje się na samej górze czysto i bez żadnych podpór.

2. **Druk bez podpór (No Supports Required)**:
   - Dzięki usunięciu sztucznej szyjki przed krzywkami (czerwona strzałka) oraz przejściu z dysku czołowego przez podcięcie do kołnierza głównego, model można drukować **bez podpór** lub z minimalnym supportem pod krawędzią kołnierza głównego (kąt nawisu wynosi 90° na odcinku 2.7 mm, co wiele nowoczesnych drukarek mostkuje bez problemu; dla idealnej krawędzi zalecany jest lekki support typu tree / organic pod kołnierzem głównym).

3. **Grawerunek na pierwszej warstwie**:
   - Napisy "HUSQVARNA", "SWEDEN", litera bębna oraz znaczniki indeksujące mają głębokość wcięcia 0.4–0.5 mm.
   - Przy pierwszej warstwie o wysokości 0.20 mm zostaną one wyraźnie odwzorowane jako elegancki, czytelny deboss.

4. **Trzpień testowy (`mating_shaft_reference.stl`)**:
   - Przed wielogodzinnym drukiem pełnego bębna zaleca się wydrukowanie małego trzpienia testowego `mating_shaft_reference.stl`.
   - Trzpień posiada fabryczny luz montażowy `SHAFT_CLEARANCE = 0.15 mm`.
   - Pozwala w kilka minut sprawdzić pasowanie otworu Ø 15.6 mm oraz wpustu z wałkiem maszyny.

---

## Rekomendowane parametry w slicerze

| Parametr | Rekomendowana wartość | Uzasadnienie |
|---|---|---|
| **Materiał** | **PETG / ABS / ASA / Nylon (PA-CF)** | Część pracuje pod stałym naciskiem sprężynowego popychacza maszyny. PLA jest akceptowalne do testów geometrii, ale PETG/ABS/ASA zapewnią wieloletnią trwałość zmęczeniową i odporność na oleje maszynowe. |
| **Wysokość warstwy** | **0.12 mm – 0.16 mm** (pierwsza: 0.20 mm) | Cieńsza warstwa zapewnia gładkie przejścia na zębach krzywki i brak schodkowania przy ruchu czujnika ściegu. |
| **Liczba obrysów (Walls / Perimeters)** | **4 – 5 obrysów** | Zęby krzywki i kołnierze powinny być wykonane niemal z litego materiału (100% obrysów w strefie zębów). |
| **Wypełnienie (Infill)** | **40% – 50% Gyroid** | Zapewnia wysoką sztywność izotropową i odporność na skręcanie pod wpływem napędu wałka. |
| **Chłodzenie** | 40–60% dla PETG, 100% dla PLA | Zapewnia ostre, równe wierzchołki zębów bez podwijania krawędzi. |
| **Prędkość druku ścian zewnętrznych** | **30 – 45 mm/s** | Niska prędkość na obrysach zewnętrznych drastycznie poprawia precyzję wymiarową zębów i gładkość pracy czujnika. |

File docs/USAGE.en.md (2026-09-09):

# Operating Instructions — Installation, Service Calibration, and Usage of Stitch Drums

Applies to stitch drums (**A1, B1, C1, D**) for **Husqvarna Automatic 21E** and related models in the family (19, 20, 21A) equipped with a stitch cam bay.

---

## Drum Construction and Mechanism Contact

* **Central Bore and Internal Keyway:** The drum features a full-length through-bore (Ø 15.6 mm, $R = 7.8\text{ mm}$) that slides directly onto the machine's drive shaft. An internal keyway (width 4.5 mm, depth 2.2 mm, $Z \in [6.4, 26.0]\text{ mm}$) engages the shaft's drive key to lock rotation.
* **Stitch Edge Tracks:** Five axial tracks feature profiled cam edges. The machine's spring-loaded follower rides directly along the outer perimeter, translating radial cam swing into lateral needle bar deflection.
* **Baseline and Amplitude:** The crest of each tooth (`EDGE_MAX_R = 17.03 mm`) represents zero needle swing (straight stitch baseline). The root of the valley (`EDGE_MIN_R = 14.20 mm`) represents full rightward swing (radial tooth swing `EDGE_SWING = 2.83 mm`).

---

## Factory Cam Replacement Procedure (from Husqvarna 21E Manual, pp. 28 & 30)

1. **Set Straight Stitch:** Turn the zigzag width dial to `0` (*rettsöm*).
2. **Select Position 5:** Shift the stitch selector lever (*Mönstervelger*) to **position 5**.
   > [!IMPORTANT]
   > Setting the selector to position 5 is essential — it relieves follower spring tension and allows the retaining arm to swing clear.
3. **Open Access Hatch:** Open the inspection door at the rear of the machine arm (fig. 39).
4. **Remove Cam:**
   * Grip the drum with the right thumb and index finger.
   * With the middle finger, lift the retaining arm (*A*, fig. 40) into the upright vertical position.
   * Pull the drum axially off the drive shaft.
5. **Install New Cam:**
   * Slide the new drum onto the shaft with the **letter (A, B, or C) facing straight up**.
   * Push the drum fully home until the retaining arm drops into the index notch on the flange (*A*, fig. 38).
   * Close the inspection door.

---

## Service Adjustments and Factory Tolerances (from Class 21 Service Manual)

1. **Follower Play Calibration (Service Manual, p. 1):**
   * With stitch width set to `0` and stitch selector at `5`, the follower contacts the high point of the cam (`EDGE_MAX_R = 17.03 mm`).
   * The play between the follower and the cam crest must be adjusted to *minimum play* using the lever clamp screw.
2. **Needle Centering (Service Manual, p. 3):**
   * Center position in the throat plate hole is fine-tuned using follower adjusting screw 1 (Fig. 4).
3. **Never Run Without a Cam (*OBS!*, User Manual p. 31):**
   > [!CAUTION]
   > **Never run the machine without a stitch drum installed!** Running the machine empty will cause the follower to strike the bare shaft, potentially damaging the needle bar drive mechanism.

---

## Initial Testing After Installation

1. Turn the handwheel by hand for 2–3 full cycles before engaging the motor to verify smooth needle bar motion.
2. Test stitch selector positions 1–5 with the needle stationary at its top dead center.
3. Perform test stitching on scrap fabric using the appropriate presser foot (for dense satin patterns, the **S 15801** embroidery foot with underside clearance is recommended).

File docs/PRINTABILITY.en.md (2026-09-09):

# Printability analysis

*(Polish original: [`PRINTABILITY.md`](PRINTABILITY.md))*

## Geometry verification method

No mesh-repair tools available in this environment (e.g. admesh, Meshmixer). The primary
verification used OpenSCAD's built-in CGAL report after a full render (`--render`, the exact
engine, not the preview one):

```
Simple:  yes
```

`Simple: yes` means the solid is a valid 2-manifold (closed, no self-intersections) — this is
effectively the "is this mesh fit for 3D printing" test at the topology level. All four files
(`cam_A.scad`, `cam_B.scad`, `cam_C.scad`, `cam_D.scad`) pass this test.

In addition, a cross-section was generated for every position of every set
(`docs/renders/cam_*_cross_section.png`, `projection(cut=true)` at the barrel's mid-height) —
direct proof of the actual edge shape, independent of how the 3D preview happens to render
(see point 3 in the problem history below).

## History of the problems found and fixed

### 1. Wall too thin (fixed, later superseded by approach #3)

The first version of the parameters left about 0.17 mm of wall on the outer-surface side at
the most strongly deflected profiles — practically a breach all the way through, too little
for FDM.

### 2. Groove completely hidden inside the material (fixed, later superseded by approach #3)

An attempt to fix problem #1 resulted in a groove that stopped reaching the outer surface —
non-functional, since the follower pin approaches the groove from outside.

### 3. Wrong mechanism model — a narrow groove instead of a profiled edge (functional bug, fixed for good)

Even after fix #2 (the groove correctly opened to the outside), the design was **still
mechanically wrong**: it was a narrow (2.2 mm), shallow channel cut into the wall of an
otherwise full-diameter cylinder (Ø 33.94 mm over most of the surface). Comparing this against
the real appearance of set A (`docs/renders/cam_A_iso.png`) showed the real mechanism is
different: **the cylinder's edge itself, at each of the 5 positions, is shaped as the stitch
profile** (visible, deep teeth all around the circumference), not hidden in the middle of a
full-diameter body. The machine's sensor/follower rides directly on this edge — a classic edge/
plate cam, not a channel with something "floating" inside the material.

**Fix #3**: each of the 5 positions is now a separate solid extruded (`linear_extrude`) from a
polygon whose outline IS DIRECTLY the stitch profile — the radius varies from
`EDGE_MAX_R = MAIN_R` (shallow) to `EDGE_MIN_R` (deep). Verified visually (isometric views
clearly show teeth, just like set A) and by cross-section.

### 4. Collars between positions and a full-length shaft bore — two further bugs found after a more precise measurement of the original (fixed)

A precise radius scan every 0.1–0.25 mm along the full length of original A (instead of just a
few cross-sections) revealed two more discrepancies against the real structure:

- **Collars between positions**: in the original, the 5 stitch positions sit **directly
  adjacent to each other, with no gap at all**. An earlier version inserted a narrow (0.8 mm)
  separating collar between them — removed.
- **No through-bore**: cam A **does not have** a central shaft bore running its full length.
  Instead it has: a shaft hole (r≈7.8 mm, depth ~2.5 mm) cut into the face of the large
  flange, and a separate, multi-step mounting spindle (several diameters: 14.97 → 9.75 →
  13.97 → 7.75 mm) between the large flange and the toothed section — see
  `docs/DIMENSIONS.en.md`. An earlier version modeled this as a simple full-length hole, which
  was a wrong simplification affecting the real mounting in the machine.

**Final fix**: `cam_common.scad` now reproduces the exact stepped spindle profile (a series of
`cylinder(r1=...,r2=...)`) and the shaft hole (instead of a through-hole), and stitch positions
sit directly adjacent with no gap (`BAND_LEN` computed without collars). Verified directly
against the STL data (a radius scan confirms every segment of the spindle) — see
`docs/renders/`.

### 5. Sensor deflection range exceeded the mechanism's real reach (fixed, later refined with photos)

`EDGE_MIN_R` was earlier set to 6.5 mm — a value chosen purely for print-strength reasons (so
a tooth valley wouldn't be too thin), **with no reference to how far the sensor/follower can
physically reach in the real machine**. A full radius scan of the entire toothed section of
original A (the STL file, a third-party replica) showed a range of **[7.71 mm, 17.03 mm]**.
After the user's photos of the physical drum arrived and the notch depth was compared against
the flange's known diameter as a scale — the real valley depth turned out to be shallower.
Corrected to `EDGE_MIN_R = 12.0 mm` (see `docs/STITCH_DESIGN.en.md`) — still an estimate (no
hard scale in the photos), but closer to the physical drum than the STL replica alone.

**Fix**: `EDGE_MAX_R = 17.03`, `EDGE_MIN_R = 12.0`. Each of the 15 B/C/D profiles (the
`*_pos1..5` functions in `cam_B/C/D.scad`) scales its amplitude WITHIN this range (coefficients
0.3–0.9 from `docs/STITCH_DESIGN.en.md`), so no pattern asks the sensor to deflect beyond its
reach.

### 6. Grooves, prismatic keyway, and engraving added based on photos of the physical drum

After receiving photos of the real drum A (see `docs/DIMENSIONS.en.md`, "Corrections based on
photos..." section), three elements not visible in the STL mesh of set A alone were added:

- **Ring of horizontal grooves on the large flange** (`ring_grooved()` in `cam_common.scad`) —
  instead of a smooth cylinder. Printability: horizontal grooves (perpendicular to the axis)
  printed with the axis vertical are standard, trouble-free FDM geometry — no overhangs. **The
  exact dimensions should be confirmed by comparison against the real drum** — depth/spacing
  were chosen visually from photos, not measured.
- **Prismatic keyway in the shaft hole** — a slot cut OUTWARD from the round hole (not a rib
  protruding inward, see `docs/DIMENSIONS.en.md` — direction fixed after the user's
  correction). Printability: just an extra cut-out space across the hole, no overhangs, no
  supports. **To be verified by fitting against the real shaft** —
  `tools/openscad/mating_shaft_reference.scad` now has a matching protruding key.
- **Engraving** ("HUSQVARNA" + "SWEDEN" + the set's letter) — shallow (0.7 mm), on the flat
  face, no effect on printability — as before.

### 7. Three geometry fixes after the user's annotations on a render (fixed)

Holding the physical drum A, the user marked up a render with three arrows (see
`docs/DIMENSIONS.en.md`, "Corrections based on the user's annotations..." section):

- **Red arrow** — the stepped mounting spindle (Y=3.2–9.7, narrowing down to ~7.75 mm) created
  an unintended gap in the render that doesn't exist on the physical part. Fixed:
  `mounting_neck()` is now a single, smooth taper straight to `EDGE_MIN_R`, with no segment
  narrower than the tooth valley. Printability: a single taper is simpler and safer to print
  than the previous three alternating narrowings/widenings.
- **Yellow arrow** — the feature previously modeled as a screw thread (a helix) **is not a
  thread**. Fixed: replaced with `ring_grooved()` (see point 6 above) — simpler, more reliable
  print geometry than a spiral thread.
- **Blue arrow** — the engraved flange (`BOSS0`) now has a diameter equal to the maximum cam
  amplitude (`BOSS0_R = EDGE_MAX_R = 17.03 mm`, previously 14.97 mm). Printability: no change —
  still a full cylinder at the bottom of the solid.
- **Chamfer on the face** (`CHAMFER_LEN` in `boss0_plain()`) — a small bevel on the top edge of
  the face, printed with no overhangs (the cone angle is much gentler than the typical 45°
  limit).

### Auxiliary part for verifying the fit

[`tools/openscad/mating_shaft_reference.scad`](../tools/openscad/mating_shaft_reference.scad)
— a simple test pin reproducing only the hole and prismatic key (with a small
`SHAFT_CLEARANCE`), to print and check the fit **before** printing a whole drum (a faster,
cheaper test than reprinting an entire cam if the key turns out to be sized wrong).

## Print orientation

**Recommended orientation: barrel axis vertical (as written in the files — the Z axis), the
larger flange (Ø 29.94 mm, the side with the engraved letter) on the bed.**

Reasons:
- The shaft hole in the face prints horizontally, layer by layer, like any other hole printed
  perpendicular to the axis — no bridging.
- The transition into the toothed section is now a single, smooth taper from the grooved ring
  down to the tooth valley — simpler than the earlier alternating narrowings/widenings, and
  standard, trouble-free FDM geometry without supports.
- The taper at the far end is inward — always trouble-free.

**Known geometric imperfection**: between adjacent stitch positions (with no separating
collar — see above), the edge radius can change fairly abruptly at the boundary between two
positions, if one ends on a deep "valley" and the next starts at a shallow point. This is a
local, single-layer effect (similar to what's seen on original A), usually printable without
supports, but it's worth inspecting these boundaries after printing and lightly cleaning them
up if needed.

**No supports are needed.**

Printing the part flipped (small flange on the bed) is discouraged — then the transition
Ø20.6 → Ø33.94 mm would be a single ~6.7 mm outward step around the full circumference, too
much for a clean print without supports.

## Set-letter marking

The letter (`A`/`B`/`C`/`D`) is engraved (cut to a depth of 0.7 mm) into the flat face of the
larger flange — so in the recommended print orientation it ends up **facing the bed**. This is
a deliberate, common approach (identification engraving on the underside of a print) — to read
it, turn the finished part upside down. The engraving has no effect on printability (shallow,
0.7 mm, creates no overhangs).

## Print settings (proposed, to be verified)

| Parameter | Value | Note |
|---|---|---|
| Layer height | 0.12–0.16 mm | finer layers = better fidelity of the tooth edge |
| Material | PETG or ABS | better wear/heat resistance than PLA for regular use in the machine; PLA is fine for a fit test |
| Infill | 40–60% | the teeth work under mechanical load (sensor/follower) |
| Perimeters | 3 min. | extra strength around the hole and the teeth |
| Supports | none | see rationale above |
| Brim/skirt | a 3–5 mm brim recommended | stabilizes a tall, narrow part during printing, given it later rotates under load |
| Orientation | axis vertical, large flange down | see above |

## Steps after printing

1. Check the fit of the shaft hole (with its keyway) and the tapered transition in the machine —
   start with the `mating_shaft_reference.scad` auxiliary part, cheaper than a whole drum.
   FDM prints often come out slightly smaller than nominal (material shrinkage); lightly sand/
   fit as needed.
2. Check and, if needed, clean up local over-extrusion at the boundaries between adjacent
   stitch positions (see above).
3. Check that the sensor/follower moves smoothly along the edge — smooth out any roughness
   with a small needle file.
4. Compare the deflection at the "reference zigzag" position against set A — if it differs
   significantly, adjust `EDGE_MAX_R`/`EDGE_MIN_R` in `cam_common.scad` and reprint.

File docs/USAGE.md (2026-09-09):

# Instrukcja obsługi — montaż, regulacja i użytkowanie bębnów ściegowych

Dotyczy bębnów ściegowych (**A1, B1, C1, D**) dla maszyn **Husqvarna Automatic 21E** oraz pokrewnych modeli z rodziny (19, 20, 21A) wyposażonych w gniazdo bębna ściegowego.

---

## Budowa bębna i zasada kontaktu z mechanizmem

* **Otwór centralny i wpust:** Bęben posiada centralny otwór przelotowy na wylot (Ø 15.6 mm, $R = 7.8\text{ mm}$), wsuwany bezpośrednio na wałek napędowy maszyny. Od strony tylnego kołnierza montażowego wycięty jest wewnętrzny wpust (szer. 4.5 mm, głęb. 2.2 mm, $Z \in [6.4, 26.0]\text{ mm}$), który blokuje obrót bębna na klinie wałka.
* **Krawędzie ściegowe:** Na 5 pozycjach osiowych znajdują się profilowane krawędzie zębate. Palec wodzika (*follower*) jeździ bezpośrednio po obwodzie krawędzi, przenosząc wychylenie poprzeczne na ramę igielnicy.
* **Pozycja bazowa:** Szczyty zębów (`EDGE_MAX_R = 17.03 mm`) odpowiadają zerowemu wychyleniu igły (ścieg prosty). Dna dolin (`EDGE_MIN_R = 14.20 mm`) odpowiadają pełnemu wychyleniu w prawo (amplituda radialna `EDGE_SWING = 2.83 mm`).

---

## Fabryczna procedura wymiany bębna (wg instrukcji Husqvarna 21E, str. 28 i 30)

1. **Ustawienie ściegu prostego:** Ustaw pokrętło szerokości zygzaka na `0` (*rettsöm*).
2. **Ustawienie pozycji 5:** Przesuń dźwignię wybieraka wzorów (*Mönstervelger*) **na pozycję 5**.
   > [!IMPORTANT]
   > Ustawienie wybieraka na 5 jest niezbędne — zwalnia ono nacisk sprężyny wodzika i umożliwia swobodne odchylenie ramienia ustalającego.
3. **Otwarcie klapki:** Otwórz drzwiczki inspekcyjne z tyłu korpusu maszyny (fig. 39).
4. **Wyjęcie bębna:**
   * Chwyć bęben kciukiem i palcem wskazującym prawej ręki.
   * Środkowym palcem odchyl ramię ustalające (*A*, fig. 40) w pozycję pionową.
   * Pociągnij i zsuń bęben z wałka osiowego.
5. **Montaż nowego bębna:**
   * Wsuń nowy bęben na wałek tak, aby **wytłoczona litera (A, B lub C) była skierowana idealnie pionowo do góry**.
   * Dociśnij bęben do końca, aż ramię ustalające samoczynnie opadnie w rowek indeksujący na kołnierzu (*A*, fig. 38).
   * Zamknij klapkę inspekcyjną.

---

## Uwagi serwisowe i regulacja mechanizmu (wg Service Manual Class 21)

1. **Kalibracja luzu wodzika (Service Manual, str. 1):**
   * Przy nastawie zygzaka na `0` i wybieraku na `5`, wierzchołek zęba krzywki (`EDGE_MAX_R`) styka się z palcem wodzika.
   * Luz między palcem a wierzchołkiem zęba powinien wynosić minimalną wartość technologiczną (*minimum play*), regulowaną śrubą zaciskową dźwigni wodzika.
2. **Centrowanie ściegu (Service Manual, str. 3):**
   * Położenie środkowe igły w otworze płytki ściegowej można precyzyjnie doregulować śrubą docisku wodzika (1 na Fig. 4).
3. **Zakaz pracy bez bębna (*OBS!*, instrukcja obsługi str. 31):**
   > [!CAUTION]
   > **Nigdy nie wolno uruchamiać napędu maszyny bez włożonego bębna ściegowego!** Brak bębna grozi uderzeniem palca wodzika o pusty wałek i mechanicznym uszkodzeniem zespołu sterowania igielnicy.

---

## Pierwsze uruchomienie po wymianie

1. Przed włączeniem silnika obróć kołem ręcznym maszyny o 2–3 pełne obroty, obserwując płynność ruchu igielnicy.
2. Przetestuj pozycje 1–5 wybieraka przy nieruchomej igle w górnym punkcie zwrotnym.
3. Wykonaj przeszycie testowe na skrawku tkaniny z odpowiednią stopką (do gęstych ściegów satynowych zalecana jest stopka do ściegów ozdobnych **S 15801** z wybraniem od spodu).

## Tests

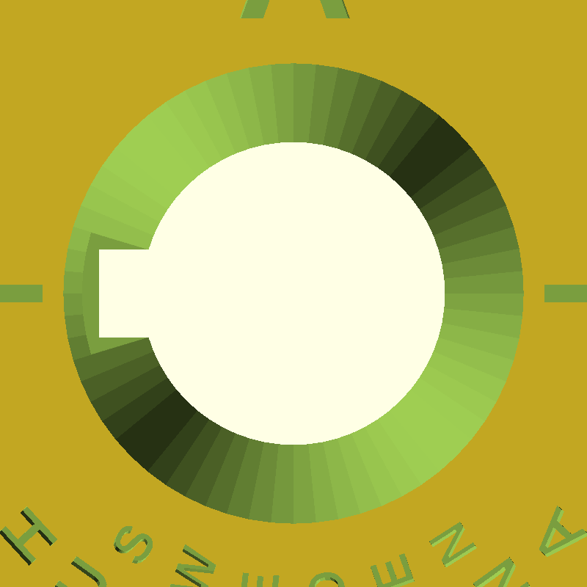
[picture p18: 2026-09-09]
docs/renders/test_label.png

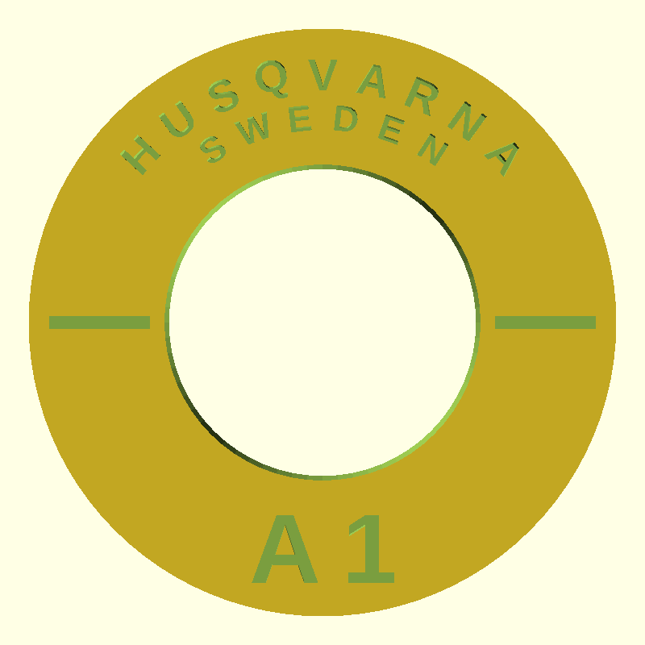
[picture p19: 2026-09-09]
docs/renders/test_text.png

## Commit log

2026-09-03 Add cam sets B, C, D with mechanical geometry from reference set A
    - Extract mechanical dimensions (bore, OD, length, end bosses) from the
    thing:6018240 (Viking 21a Basic Stitch Cam) STL via direct mesh analysis.
    - Discover the real mechanism is a barrel/drum cam (not a flat disc): a
    cylindrical groove open to the outer surface, with 5 axial follower
    positions, not a single flat profiled disc.
    - Design three new, original stitch pattern sets (B, C, D) with matching
    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
    [assembly_view.scad, cam_A_V21ZZ3Z.stl, cam_A_cross.scad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]
2026-09-03 Add combined assembly render (A+B+C+D)
2026-09-03 Fix mechanism: cam edge is the stitch profile, not a hidden groove
    The follower/sensor rides directly on the outer edge of the cam (an
    edge/plate cam, matching the real appearance of reference set A - deep,
    visible teeth separated by narrow collars), not inside a shallow slot cut
    into an otherwise full-diameter cylinder. The previous groove-based design
    was geometrically valid but mechanically wrong: most of the surface stayed
    at full diameter, so a real follower would never register meaningful
    deflection.
    Each of the 5 positions is now a linear_extrude of a polygon whose outline
    directly is the stitch waveform (EDGE_MAX_R shallow / EDGE_MIN_R deep,
    still keeping a safe minimum wall to the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
    [cam_B.stl, cam_C.stl, cam_D.stl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]
2026-09-03 Match B/C/D mounting geometry to the real structure of reference set A
    A fine-grained radius scan (0.1-0.25 mm steps) along the full length of the
    reference STL - prompted by user feedback that the previous B/C/D geometry
    still looked wrong - revealed two more mismatches with reality:
    - The 5 stitch positions sit directly adjacent in the original, with no
    separating collar between them. Remove the 0.8mm collar the previous
    version inserted between every position.
    - Set A has no through-bore for a shaft at all. What looked like a "bore"
    was actually two separate features: a blind mounting socket cut into the
    face of the large flange, and a multi-diameter stepped spindle (several
    di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
    [cam_B.stl, cam_C.stl, cam_D.stl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]
2026-09-03 Clamp stitch amplitude to the follower's real measured travel range
    EDGE_MIN_R was 6.5mm, chosen only for print-strength reasons with no
    reference to how far the machine's follower can actually travel. A full
    radius scan of the entire toothed section of reference set A (Y=9.7-24.25)
    shows the edge radius never leaves [7.71mm, 17.03mm] anywhere in the
    original - that is the follower's real, hard mechanical range, not a
    cosmetic parameter.
    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
    [cam_B.stl, cam_C.stl, cam_D.stl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]
2026-09-09 Rename to Husqvarna 21E Stitch Drum Generator, add bilingual docs, native A, mating shaft, key fix
    Major changes driven by photos of the user's own physical drum A
    (references/husqvarna_photos_A/) and follow-up clarifications:
    - Rename the project "Generator bebnow sciegowych do Husqvarna 21E /
    Husqvarna 21E Stitch Drum Generator" (the user's own machine, not just
    the thing:6018240 source title) and make README.md fully bilingual
    (PL/EN in one file). Add English mirrors of every doc (*.en.md).
    - Add docs/CREATING_NEW_DRUMS.md and tools/openscad/cam_template.scad so
    the project is explicit about being an open generator, not a closed
    four-pattern set - anyone can copy the template a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
    [cam_A.scad, cam_A.stl, cam_C.stl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]
2026-09-09 Fix mounting geometry per user annotations on physical drum A
    The user, holding the physical drum A, marked up a render with three
    arrows and a written explanation - the most direct correction source in
    this project (physical part vs. render, not a photo interpreted visually):
    - Red arrow: the stepped mounting spindle (formerly stepping down to
    ~7.75mm between the flange and the toothed section) left a gap in the
    render that does not exist on the real part. Replaced with a single
    smooth taper straight into the tooth valley radius - mounting_neck() no
    longer has any segment narrower than EDGE_MIN_R.
    - Yellow arrow: the ridged band next to the flange is NOT a screw thread.
    Replaced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
    [cam_A.stl, cam_B.stl, cam_C.stl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]
2026-09-09 feat: add universal stitch drum generator with 35+ stitch catalog and historical A1/B1/C1 models
    [assembly_view.scad, cam_A.scad, cam_A.stl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]
2026-09-09 fix: align drum generator with repository models and add amateur-friendly 3D GUI app
    [cam_D.scad, cam_D.stl, cam_E.scad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]
2026-09-09 feat: in-browser real-time 3D drum generator with direct STL export and GitHub Pages app
2026-09-09 ui: dynamically update slot number on stitch selection cards
2026-10-23 fix: watertight drum STLs, browser mesh matches OpenSCAD, consistent stitch catalogue
    - STL (OpenSCAD 2021/CGAL): rear collar and keyway slivers came out as 10 separate bodies
    (not watertight). cam_common.scad joins the sections with JOIN_EPS = 0.01 mm; cam_A..E
    re-rendered, each is one watertight body.
    - Browser generator (index.html): rings that coincide share vertices (no zero-area
    triangles), consistent outward winding, disc grooves at the same Z as disc_grooved(),
    rectangular 4.5 x 2.2 mm key slot instead of slanted walls; dimensions now taken from
    the cam_common.scad constants.
    - Stitch catalogue: stitch_catalog.scad had 5 stale formulas (5, 6, 7, 12, 27) that did not
    match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
2026-10-23 feat(generator): material / finish selector like the Elna cam studio
    Original Husqvarna (black), PETG (recommended), ASA/ABS, PA-CF, PA, tough resin, PLA (test only):
    preview colour and surface, print temperatures and settings from docs/PRINTABILITY.md, choice
    remembered and written into the downloaded .scad. Neutral lights and flat shading so the material
    colour is true and tooth edges are crisp. Geometry and STL unchanged.
2026-10-23 fix: browser drum = OpenSCAD at step walls (degree-exact sin/cos), track cards fit the screen
    - sign() stitches (13 ladder = D pos. 3, 31 satin blocks = C pos. 3): OpenSCAD sin(180)=0 gives
    sign=0 at the jump, JS Math.sin(pi)=1.2e-16 gave +-1, so step walls moved by one 3.75 deg segment
    (browser STL differed from models/generated/cam_C/D.stl by up to 1.1 mm). JS now uses
    sinDeg/cosDeg exact like OpenSCAD; blockSatin no longer forces sign(0) to 1.
    - check_stitch_formulas.py also samples at the drum grid angles i*360/96 (would have caught it);
    UTF-8 output on the Windows console.
    - .tracks-deck: minmax(0, 1fr) - position 5 card was 14 px off-screen at 1400 px.
    Browser presets A1/B1/C1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
